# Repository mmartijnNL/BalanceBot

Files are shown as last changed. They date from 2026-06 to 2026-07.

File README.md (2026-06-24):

This project now targets a direct motor-control architecture using the `SimpleFOC` library:
- LOLIN32LITE runs both FOC loops and high-level coupling logic
- Two AS5600 magnetic sensors provide shaft feedback over I2C
- Two 3PWM BLDC drivers are controlled directly from the LOLIN32LITE

Parts list
MPU6050 GY-521 6DOF IMU (3-axis accelerometer + gyroscope)

2x 2804 BLDC hollow-shaft motor 
2x AS5600 magnetic encoder set (FOC support)

2x Simple FOC mini

LOLIN32 Lite (ESP32)

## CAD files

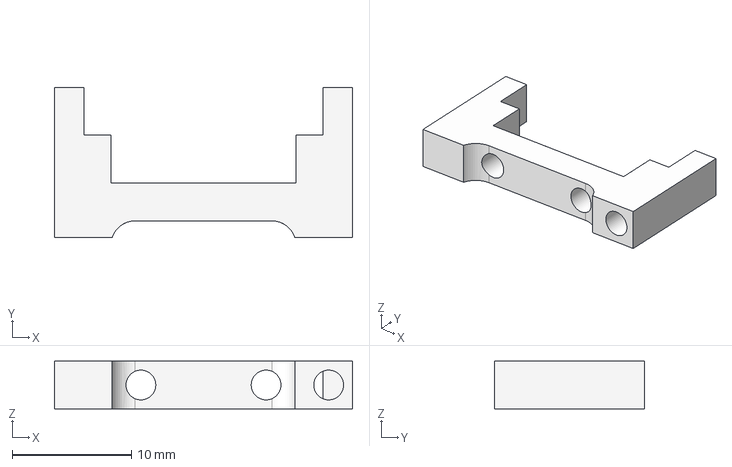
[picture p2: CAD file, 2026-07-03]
3D Models/Part Studio 1 - Lolin StandOff.step
25.0 x 12.6 x 4.00 mm

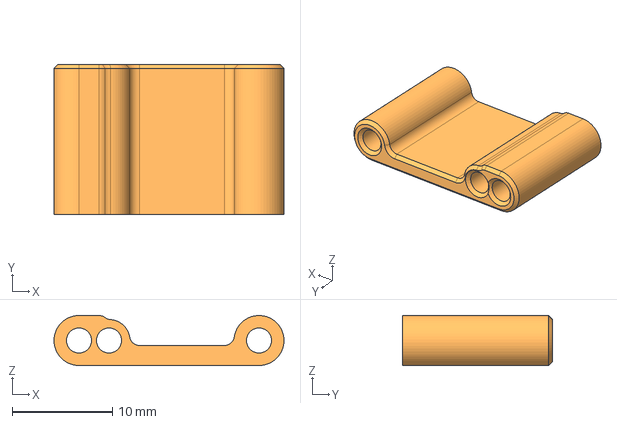
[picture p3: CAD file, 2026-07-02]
3D Models/Part Studio 1 - Bottom StandOff.step
23.0 x 15.0 x 5.00 mm

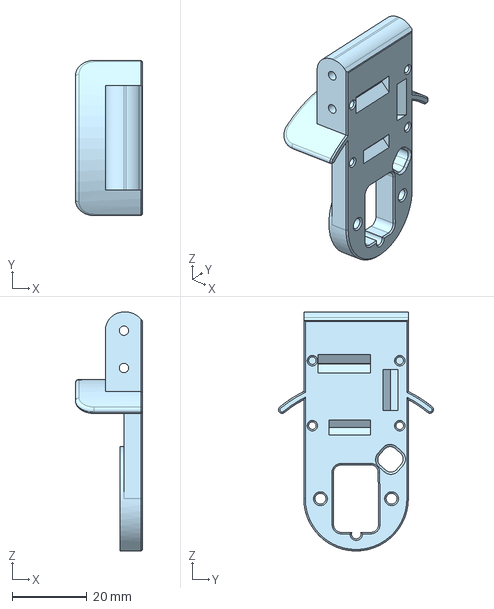
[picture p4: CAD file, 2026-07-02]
3D Models/Part Studio 1 - Leg.step
18.0 x 41.6 x 64.0 mm

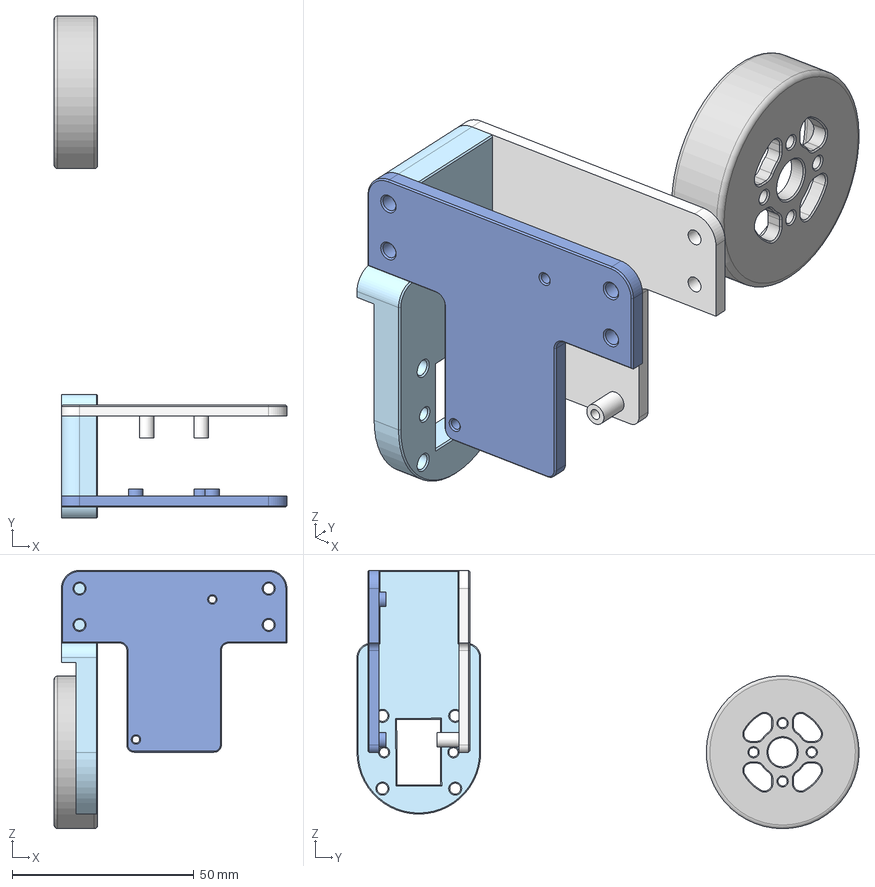
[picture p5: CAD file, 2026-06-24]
3D Models/BalanceBot2.step
64.0 x 138.0 x 71.0 mm

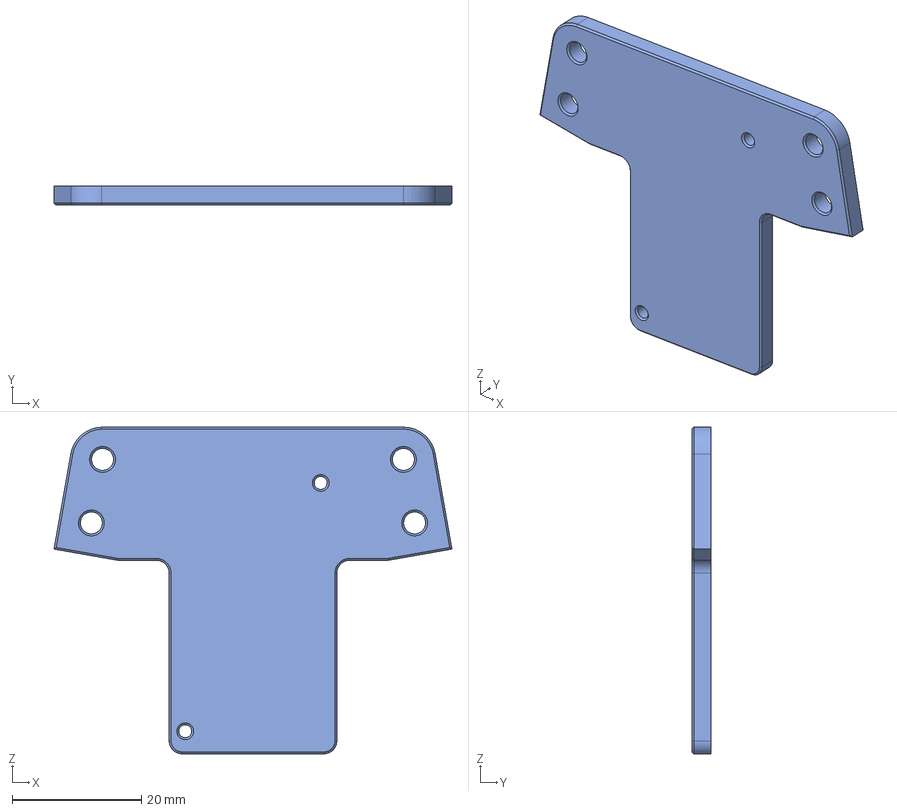
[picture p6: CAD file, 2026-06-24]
3D Models/Part Studio 1 - Plate Front.step
61.7 x 3.00 x 50.6 mm

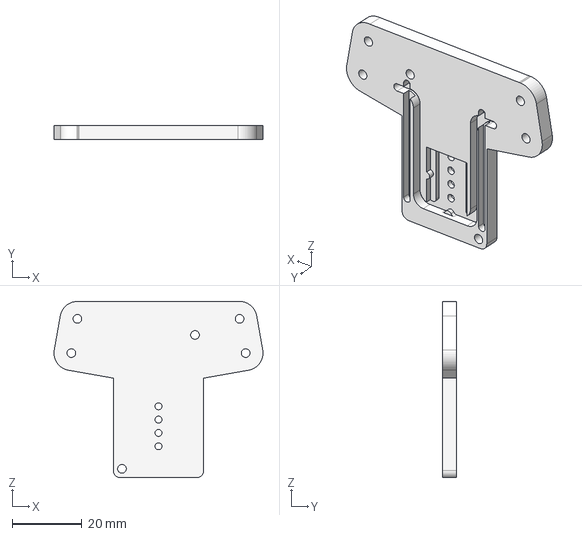
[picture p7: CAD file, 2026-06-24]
3D Models/Part Studio 1 - Part 4.step
60.1 x 4.00 x 50.6 mm

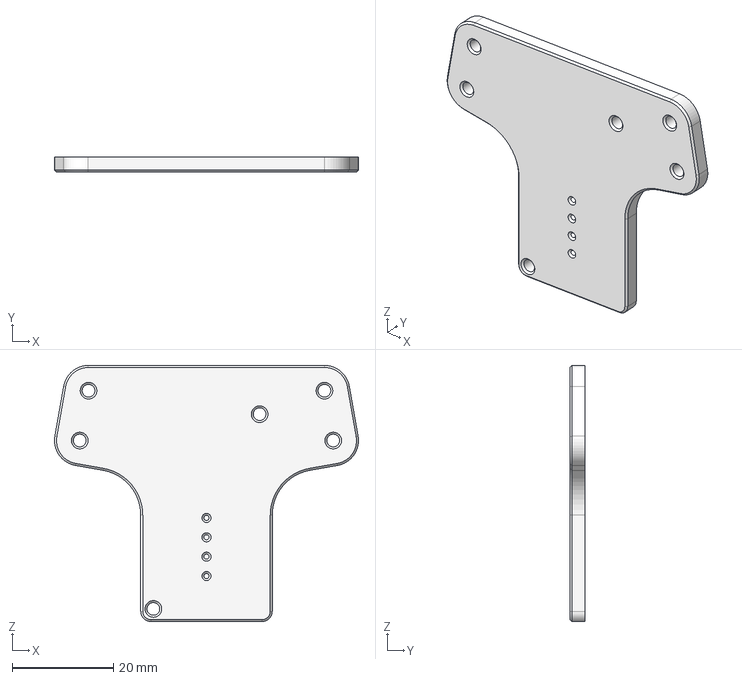
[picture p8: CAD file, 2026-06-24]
3D Models/Part Studio 1 - Plate Front v2.step
60.1 x 3.00 x 50.6 mm

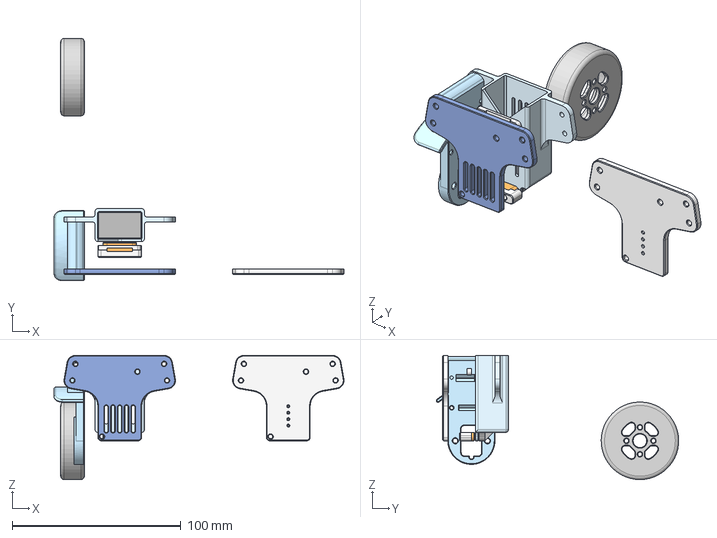
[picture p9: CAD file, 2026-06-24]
3D Models/Part Studio 1.step
172.0 x 143.8 x 73.6 mm

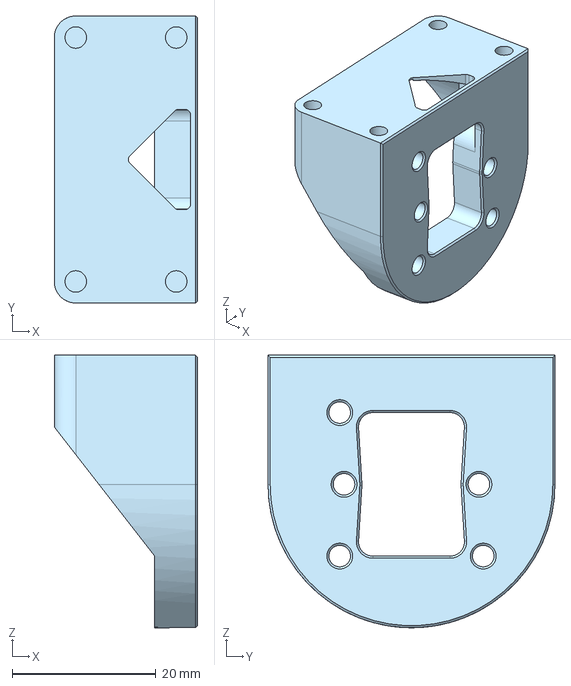
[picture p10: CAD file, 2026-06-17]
3D Models/Part Studio 1 - Motor Shell.step
20.0 x 40.0 x 38.0 mm

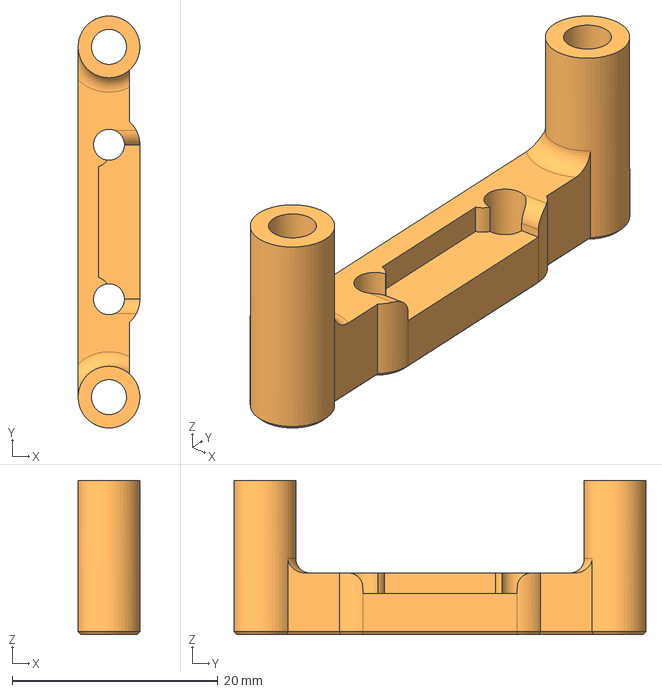
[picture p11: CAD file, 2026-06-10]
3D Models/Part Studio 1 - MPU Stand Off.step
6.00 x 40.0 x 15.0 mm

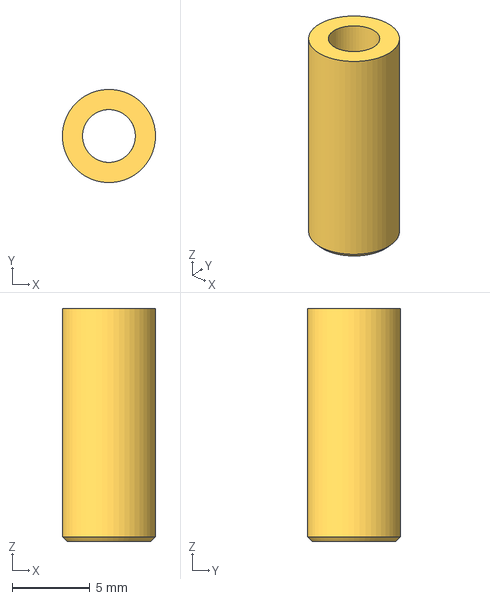
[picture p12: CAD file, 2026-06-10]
3D Models/Part Studio 1 - Stand Off.step
5.99 x 6.00 x 15.0 mm

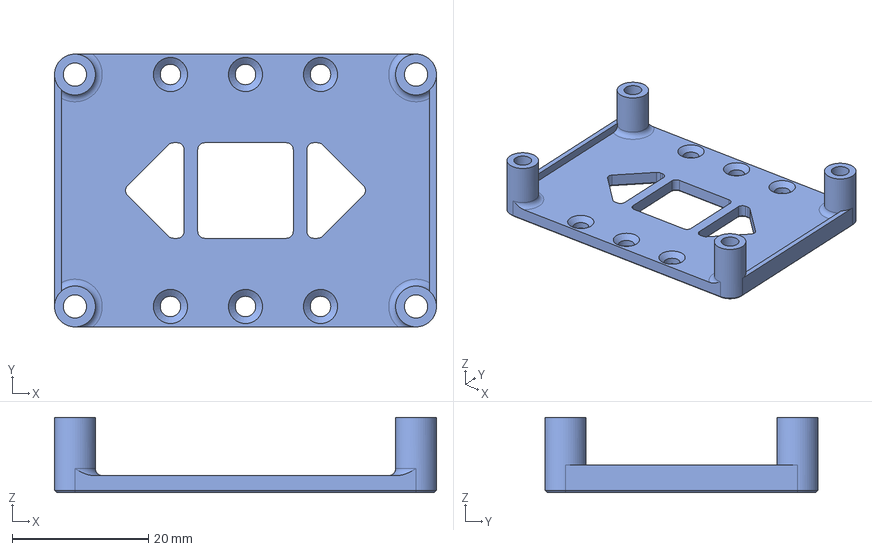
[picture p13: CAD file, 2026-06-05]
3D Models/Part Studio 1 - Bottom Plate.step
56.0 x 40.0 x 11.0 mm

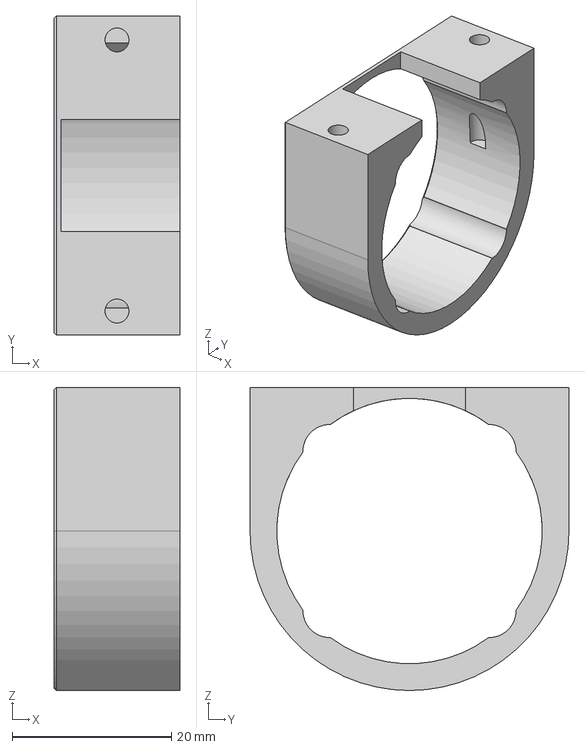
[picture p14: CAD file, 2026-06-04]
3D Models/Part Studio 1 - Middle Shell.step
15.8 x 40.0 x 38.0 mm

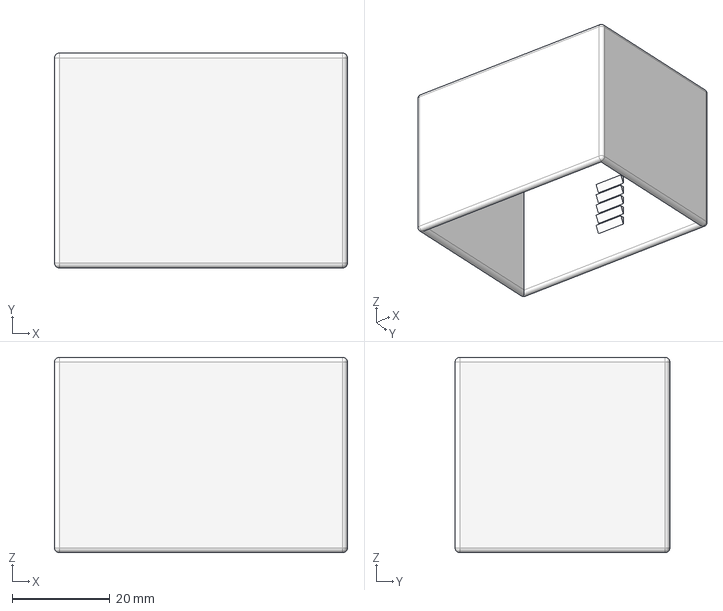
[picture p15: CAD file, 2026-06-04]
3D Models/Part Studio 1 - Top Shell.step
60.0 x 44.0 x 40.0 mm

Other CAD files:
3D Models/Part Studio 1 - Battery Plate.step
3D Models/Part Studio 1 - Lego Hub.step
3D Models/Part Studio 1 - Top Shell.3mf

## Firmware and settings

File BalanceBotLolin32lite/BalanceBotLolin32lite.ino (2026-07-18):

#ifndef BALANCE_BOT_LOLIN32LITE_INO
#define BALANCE_BOT_LOLIN32LITE_INO

#include <Arduino.h>
#include <SimpleFOC.h>
#include <MPU6050_light.h>
#include <Wire.h>
#include <cmath>
#include <cstdio>

namespace {

// PID tuning values
constexpr float kP = 9.0f;  // Proportional: stiffness, how hard the bot fights tilt
constexpr float kI = 0.0f;  // Integral: corrects steady-state lean / drift
constexpr float kD = 0.02f;  // Derivative: damping, reduces oscillation

constexpr float kWheelVelocityDampingGain = 0.06f;

constexpr float kSupplyVoltage = 16.8f;         // 4S LiPo: full=16.8 low=14
constexpr float kMotorVoltageLimit = 8.0f;
constexpr float kLeftMotorDirection =   1.0f;   // Reverse if needed
constexpr float kRightMotorDirection =  -1.0f;  // Reverse if needed

// Radio Control
bool kEnableRcReceiver = false;
constexpr float kRcThrottleAngleGain =  40.0f;
constexpr float kRcSteerTorqueGain =    20.0f;

constexpr bool kEnableTelemetry = true;
constexpr unsigned long kTelemetryPeriodMs = 50UL;
constexpr unsigned long kSerialBaudRate = 460800UL;
constexpr float kDegreesToRadians =     0.017453292519943295f;
constexpr float kRadiansToDegrees =     57.29577951308232f;

TwoWire i2cLeft = TwoWire(0);
TwoWire i2cRight = TwoWire(1);

MagneticSensorI2C leftSensor = MagneticSensorI2C(AS5600_I2C);
MagneticSensorI2C rightSensor = MagneticSensorI2C(AS5600_I2C);
MPU6050 imu = MPU6050(i2cLeft);

BLDCMotor leftMotor = BLDCMotor(7);     // 7 pole pairs
BLDCDriver3PWM leftDriver = BLDCDriver3PWM(23, 18, 5, 17);

BLDCMotor rightMotor = BLDCMotor(7);    // 7 pole pairs
BLDCDriver3PWM rightDriver = BLDCDriver3PWM(25, 26, 27, 14);

float startAngle = 0.0f;
float errorAngleIntegral = 0.0f;
float lastErrorAngle = 0.0f;
unsigned long lastTelemetryMs = 0UL;
unsigned long lastLoopMs = 0UL;

float clampAbs(float value, float limit) {
    if (value > limit) return limit;
    if (value < -limit) return -limit;
    return value;
}

// Returns an angle in degrees around an axis.
float getAngle() {
    static bool initialized = false;
    static unsigned long lastMicros = 0;
    static float angle = 0.0f;

    const unsigned long nowMicros = micros();
    if (!initialized) {
        initialized = true;
        lastMicros = nowMicros;
        return angle;
    }

    // Gyro output is in deg/s, so integrate over elapsed seconds.
    const float dt = (nowMicros - lastMicros) * 1.0e-6f;
    lastMicros = nowMicros;
    angle += imu.getGyroX() * dt;

    // Keep a single-turn representation.
    while (angle >= 360.0f) angle -= 360.0f;
    while (angle < 0.0f) angle += 360.0f;

    return angle;
}

// RC receiver state — written in ISRs, read in loop()
volatile unsigned long rcThrottleRiseUs = 0UL;
volatile unsigned long rcThrottlePulseUs = 1500UL;
volatile unsigned long rcThrottleLastUpdateUs = 0UL;
volatile unsigned long rcSteerRiseUs = 0UL;
volatile unsigned long rcSteerPulseUs = 1500UL;
volatile unsigned long rcSteerLastUpdateUs = 0UL;

void IRAM_ATTR onRcThrottleChange() {
    const unsigned long now = micros();
    if (digitalRead(39) == HIGH) {
        rcThrottleRiseUs = now;
    } else if (rcThrottleRiseUs != 0UL) {
        rcThrottlePulseUs = now - rcThrottleRiseUs;
        rcThrottleLastUpdateUs = now;
    }
}

void IRAM_ATTR onRcSteerChange() {
    const unsigned long now = micros();
    if (digitalRead(36) == HIGH) {
        rcSteerRiseUs = now;
    } else if (rcSteerRiseUs != 0UL) {
        rcSteerPulseUs = now - rcSteerRiseUs;
        rcSteerLastUpdateUs = now;
    }
}

// Non-blocking RC read — returns 0 if signal is stale (>100 ms)
float getRcChannel(volatile unsigned long& pulseUs, volatile unsigned long& lastUpdateUs) {
    constexpr unsigned long kRcPulseMin = 1000UL;
    constexpr unsigned long kRcPulseMax = 2000UL;
    constexpr unsigned long kRcPulseCenter = 1500UL;
    constexpr unsigned long kRcSignalTimeout = 100000UL;  // 100 ms
    if ((micros() - lastUpdateUs) > kRcSignalTimeout) return 0.0f;
    const unsigned long pulse = pulseUs;
    const unsigned long clamped = (pulse < kRcPulseMin) ? kRcPulseMin
        : (pulse > kRcPulseMax ? kRcPulseMax : pulse);
    return static_cast<float>(static_cast<long>(clamped) - static_cast<long>(kRcPulseCenter)) / 500.0f;
}

void emitTelemetry(unsigned long nowMs,
    float angle,
    float targetAngle,
    float leftWheelVelocity,
    float rightWheelVelocity) {
    if (!kEnableTelemetry) return;
    if ((nowMs - lastTelemetryMs) < kTelemetryPeriodMs) return;

    char telemetryLine[256];
    const int n = snprintf(
        telemetryLine,
        sizeof(telemetryLine),
        // Keep each line compact so it fits typical UART TX buffers without blocking.
        "angle:%.2f,target:%.2f,left:%.3f,right:%.3f\n",
        static_cast<double>(angle),
        static_cast<double>(targetAngle),
        static_cast<double>(leftWheelVelocity),
        static_cast<double>(rightWheelVelocity));

    if (n > 0 && n < static_cast<int>(sizeof(telemetryLine))) {
        // Skip rather than block: motor loop timing is more important than telemetry.
        const int available = Serial.availableForWrite();
        if (available <= 0) return;
        if (available < n) return;
        Serial.write(reinterpret_cast<const uint8_t*>(telemetryLine), static_cast<size_t>(n));
        lastTelemetryMs = nowMs;
    }
}

}  // namespace

void setup() {
    Serial.begin(kSerialBaudRate);
    delay(250);
    Serial.println("\nBalanceBot SimpleFOC boot");

    pinMode(39, INPUT);
    pinMode(36, INPUT);
    attachInterrupt(digitalPinToInterrupt(39), onRcThrottleChange, CHANGE);
    attachInterrupt(digitalPinToInterrupt(36), onRcSteerChange, CHANGE);

    i2cLeft.begin(22, 19, 100000); 
    i2cRight.begin(32, 33, 100000);

    byte imuStatus = imu.begin();
    while (imuStatus != 0) {
        Serial.print("MPU6050 init failed, status=");
        Serial.println(static_cast<int>(imuStatus));
        imuStatus = imu.begin();
    }
    
    imu.calcOffsets(true, true);

    imu.update();

    leftSensor.init(&i2cLeft);
    rightSensor.init(&i2cRight);

    leftMotor.linkSensor(&leftSensor);
    rightMotor.linkSensor(&rightSensor);

    leftDriver.voltage_power_supply = kSupplyVoltage;
    leftDriver.init();
    rightDriver.voltage_power_supply = kSupplyVoltage;
    rightDriver.init();

    leftMotor.linkDriver(&leftDriver);
    rightMotor.linkDriver(&rightDriver);

    leftMotor.controller = MotionControlType::torque;
    rightMotor.controller = MotionControlType::torque;

    leftMotor.voltage_limit = kMotorVoltageLimit;
    rightMotor.voltage_limit = kMotorVoltageLimit;

    leftMotor.useMonitoring(Serial);
    rightMotor.useMonitoring(Serial);

    leftMotor.init();
    rightMotor.init();
    leftMotor.initFOC();
    rightMotor.initFOC();

    // Init starting angle.
    startAngle = getAngle();
    Serial.print("StartAngle:");
    Serial.println(startAngle);

    // Init loop timing
    const unsigned long nowMs = millis();
    lastTelemetryMs = nowMs;
    lastLoopMs = nowMs;

    Serial.println("Init done.");
}

void loop() {
    leftMotor.loopFOC();
    rightMotor.loopFOC();

    imu.update();

    const float angle = getAngle();

    const unsigned long nowMs = millis();
    const float dtSeconds = static_cast<float>(nowMs - lastLoopMs) * 0.001f;
    lastLoopMs = nowMs;

    const float rcThrottle = getRcChannel(rcThrottlePulseUs, rcThrottleLastUpdateUs);
    const float rcSteer    = getRcChannel(rcSteerPulseUs,    rcSteerLastUpdateUs);

    // Auto enable RC control.
    if(!kEnableRcReceiver && (rcThrottle > 0.3f || rcSteer > 0.3f || rcSteer < -0.3f))
    {
        Serial.println("Enabling RC control");
        kEnableRcReceiver = true;
    }

    const float targetAngle = startAngle + ((kEnableRcReceiver ? rcThrottle : 0.0f) * kRcThrottleAngleGain);
    const float errorAngle = angle - targetAngle;

    // Integral: accumulate error over time
    errorAngleIntegral += errorAngle * dtSeconds;

    const float balanceTorqueTarget =
        (-kP * errorAngle)                     // Proportional
        - (kI * errorAngleIntegral)                     // Integral
        - (kD * (errorAngle - lastErrorAngle) / dtSeconds);          // Derivative

    lastErrorAngle = errorAngle;
        
    const float steerTorque = (kEnableRcReceiver ? rcSteer : 0.0f)  * kRcSteerTorqueGain;

    float leftTorque = balanceTorqueTarget - steerTorque;
    float rightTorque = balanceTorqueTarget + steerTorque;

    // leftMotor.move(kLeftMotorDirection * leftTorque);
    // rightMotor.move(kRightMotorDirection * rightTorque);

    emitTelemetry(
        nowMs,
        angle,
        targetAngle,
        leftMotor.shaft_velocity,
        rightMotor.shaft_velocity);
}

#endif // BALANCE_BOT_LOLIN32LITE_INO

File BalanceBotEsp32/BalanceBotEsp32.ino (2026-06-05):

#ifndef BALANCE_BOT_ESP32_INO
#define BALANCE_BOT_ESP32_INO

#include <Arduino.h>
#include <SimpleFOC.h>
#include <Wire.h>
#include <cmath>

namespace {

constexpr uint8_t kLeftI2cSdaPin = 19;
constexpr uint8_t kLeftI2cSclPin = 18;
constexpr uint8_t kRightI2cSdaPin = 23;
constexpr uint8_t kRightI2cSclPin = 5;

constexpr int kMotorPolePairs = 7;

constexpr uint8_t kLeftPwmUPin = 32;
constexpr uint8_t kLeftPwmVPin = 33;
constexpr uint8_t kLeftPwmWPin = 25;
constexpr uint8_t kLeftEnablePin = 22;

constexpr uint8_t kRightPwmUPin = 26;
constexpr uint8_t kRightPwmVPin = 27;
constexpr uint8_t kRightPwmWPin = 14;
constexpr uint8_t kRightEnablePin = 12;

constexpr float kSupplyVoltage = 12.0f;
constexpr float kMotorVoltageLimit = 12.0f;
constexpr float kFollowerVelocityGain = 10.0f;
constexpr float kMasterTorqueGain = 5.0f;
constexpr float kDeadZoneRadians = 0.2f;

TwoWire leftI2cBus = TwoWire(0);
TwoWire rightI2cBus = TwoWire(1);

MagneticSensorI2C leftSensor = MagneticSensorI2C(AS5600_I2C);
MagneticSensorI2C rightSensor = MagneticSensorI2C(AS5600_I2C);

BLDCMotor leftMotor = BLDCMotor(kMotorPolePairs);
BLDCDriver3PWM leftDriver = BLDCDriver3PWM(kLeftPwmUPin, kLeftPwmVPin, kLeftPwmWPin, kLeftEnablePin);

BLDCMotor rightMotor = BLDCMotor(kMotorPolePairs);
BLDCDriver3PWM rightDriver = BLDCDriver3PWM(kRightPwmUPin, kRightPwmVPin, kRightPwmWPin, kRightEnablePin);

float deadZone(float value) {
    return (std::fabs(value) < kDeadZoneRadians) ? 0.0f : value;
}

void initializeI2cBuses() {
#if defined(ARDUINO_ARCH_ESP32)
    leftI2cBus.begin(kLeftI2cSdaPin, kLeftI2cSclPin, 400000);
    rightI2cBus.begin(kRightI2cSdaPin, kRightI2cSclPin, 400000);
#else
    leftI2cBus.setSDA(kLeftI2cSdaPin);
    leftI2cBus.setSCL(kLeftI2cSclPin);
    leftI2cBus.begin();

    rightI2cBus.setSDA(kRightI2cSdaPin);
    rightI2cBus.setSCL(kRightI2cSclPin);
    rightI2cBus.begin();
#endif
}

}  // namespace

void setup() {
    Serial.begin(115200);
    delay(250);
    Serial.println("\nBalanceBot SimpleFOC boot");

    initializeI2cBuses();
    leftSensor.init(&leftI2cBus);
    rightSensor.init(&rightI2cBus);

    leftMotor.linkSensor(&leftSensor);
    rightMotor.linkSensor(&rightSensor);

    leftDriver.voltage_power_supply = kSupplyVoltage;
    leftDriver.init();
    rightDriver.voltage_power_supply = kSupplyVoltage;
    rightDriver.init();

    leftMotor.linkDriver(&leftDriver);
    rightMotor.linkDriver(&rightDriver);

    leftMotor.controller = MotionControlType::torque;
    rightMotor.controller = MotionControlType::velocity;

    leftMotor.voltage_limit = kMotorVoltageLimit;
    rightMotor.voltage_limit = kMotorVoltageLimit;
    rightMotor.LPF_velocity.Tf = 0.01f;
    rightMotor.PID_velocity.I = 1.0f;

    leftMotor.useMonitoring(Serial);
    rightMotor.useMonitoring(Serial);

    leftMotor.init();
    rightMotor.init();
    leftMotor.initFOC();
    rightMotor.initFOC();

    Serial.println("SimpleFOC motors ready.");
}

void loop() {
    leftMotor.loopFOC();
    rightMotor.loopFOC();

    const float leftAngle = leftMotor.shaft_angle;
    const float followerVelocityTarget = kFollowerVelocityGain * deadZone(leftAngle);
    rightMotor.move(followerVelocityTarget);

    const float masterTorqueTarget = kMasterTorqueGain * ((rightMotor.shaft_velocity / 10.0f) - leftAngle);
    leftMotor.move(masterTorqueTarget);
}

#endif // BALANCE_BOT_ESP32_INO

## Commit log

2026-05-28 cpp simulation
    [sim_stabilize.csv]
2026-05-28 actual simulation
    [sim_stabilize.csv]
2026-05-28 Sim acronym
    [sim_stabilize.csv]
2026-05-29 Added pico
2026-05-29 button fixes
2026-06-04 Step files
    [Part Studio 1 - Battery Plate.step, Part Studio 1 - Bottom Plate.step, Part Studio 1 - Lego Hub.step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]
2026-06-04 Updated diagram
    [Part Studio 1 - Top Shell.3mf]
2026-06-05 no more pico
2026-06-05 no more uart
    [Part Studio 1 - Bottom Plate.step, Part Studio 1 - MPU Stand Off.step, Part Studio 1 - Top Shell.3mf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]
2026-06-10 removed weird files
    [Part Studio 1 - Top Shell.3mf, Part Studio 1.step]
2026-06-10 rename to lolin
    [Part Studio 1 - MPU Stand Off.step, Part Studio 1 - Stand Off.step, Part Studio 1 - Top Shell.3mf]
2026-06-16 motor moves
2026-06-17 Repo cleanup
    [sim_stabilize.csv]
2026-06-17 better logging
    [Part Studio 1 - Motor Shell.step, Part Studio 1 - Top Shell.3mf]
2026-06-24 changed pins
    [BalanceBot2.step, Part Studio 1 - Bottom StandOff.step, Part Studio 1 - Leg.step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]
2026-07-02 simplified code
    [Part Studio 1 - Bottom StandOff.step, Part Studio 1 - Leg.step, Part Studio 1 - Top Shell.3mf]
2026-07-03 Enable both motors
    [Part Studio 1 - Lolin StandOff.step, Part Studio 1 - Top Shell.3mf]
2026-07-18 simplified imu test
2026-07-18 imutest works
2026-07-18 imutest startangle
